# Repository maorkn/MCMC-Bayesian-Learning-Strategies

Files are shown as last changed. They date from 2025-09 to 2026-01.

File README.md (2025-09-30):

# Beyond Diffusion: Bayesian Learning Strategies in Single-Cell Life

**A comprehensive research framework for investigating predictive learning, memory formation, and Bayesian inference at the cellular level**

This repository contains the complete codebase, experimental platforms, and documentation for the paper **"Beyond Diffusion: Bayesian Learning Strategies in Single-Cell Life"**. The project demonstrates that single-celled organisms might exhibit sophisticated learning behaviors that extend beyond simple chemical diffusion, employing Bayesian-like inference strategies for environmental prediction and adaptive responses.

---

## Table of Contents

- [Overview](#overview)
- [Repository Structure](#repository-structure)
- [Research Components](#research-components)
  - [1. MBS Simulation](#1-mbs-simulation)
  - [2. Microscope-Mounted Chemostat](#2-microscope-mounted-chemostat)
  - [3. Smart Incubator](#3-smart-incubator)
  - [4. Manuscript](#4-manuscript)
- [Key Findings](#key-findings)
- [Getting Started](#getting-started)
- [Research Applications](#research-applications)
- [Hardware Platforms](#hardware-platforms)
- [Citation](#citation)
- [License](#license)
- [Contact](#contact)

---

## Overview

This research investigates whether single-celled organisms possess the capacity for **predictive learning** through Bayesian-like inference mechanisms that operate at sub-neural scales. The project combines:

1. **Agent-Based Simulations**: Computational models comparing Markovian-Bayesian Agents (MBAs) with memory-based learning against Blind Agents (BAs) that react only to current stimuli
2. **Experimental Validation**: Two custom-built automated platforms for long-term, high-precision biological experiments
3. **Theoretical Framework**: Mathematical models of cellular learning grounded in Bayesian inference and information theory

### Core Hypothesis

Single-celled organisms can:
- **Learn temporal associations** between environmental cues and subsequent stressors
- **Form cellular memories** that influence future behavioral responses
- **Predict environmental changes** using past experience encoded in molecular states
- **Optimize fitness** through anticipatory rather than purely reactive strategies

---

## Repository Structure

```
MCMC-Bayesian-Learning-Strategies/
├── README.md                           # This file
├── Manuscript/
│   └── Draft_18_09_25.tex             # LaTeX manuscript source
├── MBS_simulation/
│   └── MBA vs BA sim/                 # Agent-based simulation framework
│       ├── README.md                  # Simulation documentation
│       ├── mba_vs_ba_sim/            # Core simulation package
│       ├── wrappers/                  # Experiment wrappers
│       └── Fig_pub/                   # Publication figure generation
├── Microscope_mounted_chemostat/
│   ├── README.md                      # Platform documentation (400+ lines)
│   ├── Firmware/                      # ESP32 MicroPython code
│   ├── Hardware/                      # PCB Gerbers + 3D models
│   └── Docs/                          # Specifications & methods
└── Smart_incubator/
    ├── README.md                      # Platform documentation (400+ lines)
    ├── Firmware/                      # ESP32 MicroPython code (21 files)
    ├── Hardware/                      # PCB schematics + 3D models
    └── Docs/                          # Specifications, methods & analysis
```

---

## Research Components

### 1. MBS Simulation

**Location**: `MBS_simulation/MBA vs BA sim/`

**Purpose**: Agent-based simulations comparing learning strategies in evolutionary contexts.

#### Key Features

- **Markovian-Bayesian Agents (MBAs)**: Organisms that maintain memory of environmental patterns and use Bayesian inference to predict future conditions
- **Blind Agents (BAs)**: Memory-less organisms that respond only to immediate stimuli
- **Moran Process**: Population dynamics simulation with fitness-dependent reproduction
- **Multiple Experimental Paradigms**: Stress tests, genetic lock-in, continuous sweeps, topology scans

#### Agent Types

| Agent Type | Memory | Learning | Prediction | Fitness Strategy |
|---|---|---|---|---|
| MBA (Markovian-Bayesian) | ✓ | ✓ | ✓ | Anticipatory preparation |
| BA (Blind Agent) | ✗ | ✗ | ✗ | Reactive only |
| MBA-Gauss | ✓ | ✓ | ✓ | Gaussian environment model |

#### Simulation Capabilities

- **Population Evolution**: Track strategy dominance over thousands of generations
- **Fitness Landscapes**: Analyze preparatory response costs and benefits
- **Parameter Sweeps**: Systematic exploration of correlation, memory cost, environment variability
- **Statistical Analysis**: Permutation tests, effect size calculations, publication-ready visualizations

#### Quick Start

```bash
cd "MBS_simulation/MBA vs BA sim"
python -m wrappers.vanilla    # Basic MBA vs BA comparison
python -m wrappers.stress     # Stress test scenarios
```

**Documentation**: See `MBS_simulation/MBA vs BA sim/README.md` for detailed usage and `CLEANED_REPOSITORY_SUMMARY.md` for architecture overview.

---

### 2. Microscope-Mounted Chemostat

**Location**: `Microscope_mounted_chemostat/`

**Purpose**: Real-time microfluidic platform for studying habituation, valence reassignment, and threshold adaptation under microscopic observation.

#### Platform Capabilities

**Experimental Control:**
- **4-Pump Peristaltic System**: Independent control of 4 culture chambers
- **Variable Flow Rates**: 0-100% PWM control (13-bit resolution)
- **Programmable Protocols**: Chemostat, turbidostat, morbidostat modes
- **Temporal Precision**: Microsecond-level timing for stimulus delivery
- **Long-Term Stability**: Continuous operation for days to weeks

**Operational Modes:**
1. **Chemostat Mode**: Constant dilution rate, steady-state growth
2. **Turbidostat Mode**: Optical density (cellpose) feedback control
3. **Morbidostat Mode**: Dynamic drug concentration adjustment
4. **Custom Protocols**: User-defined temporal sequences

**Real-Time Integration:**
- **Microscope Compatibility**: Mounts directly on inverted microscopes
- **Cellpose Integration**: Optional AI-based cell counting
- **MQTT Communication**: Remote monitoring and control
- **Live Imaging**: Synchronized with image acquisition systems

#### Hardware Specifications

| Component | Specification | Function |
|---|---|---|
| Microcontroller | ESP32-WROOM-32 (240 MHz dual-core) | System control |
| Pumps | 4× Peristaltic pumps | Media delivery (intake, waste, 2× drugs) |
| LED Control | PWM-controlled illumination | Growth chamber lighting |
| Communication | WiFi (MQTT protocol) | Remote operation |
| Cost | $250-$840 | Depending on pump choice |

#### Research Applications

- **Habituation Studies**: Long-term adaptation to repeated chemical stressors
- **Valence Reassignment**: Testing whether organisms reassign meaning to previously neutral cues
- **Threshold Adaptation**: Investigating changes in stress response thresholds
- **Chemotaxis Experiments**: Studying gradient-following behavior
- **Drug Resistance Evolution**: Real-time observation of resistance emergence

#### Quick Start

```bash
# 1. Upload firmware to ESP32
cd Microscope_mounted_chemostat/Firmware
# Use Thonny or ampy to upload *.py files

# 2. Calibrate pumps
python local_pump_calibration.py

# 3. Run experiment
python chemostat_controller.py
```

**Full Documentation**: See `Microscope_mounted_chemostat/README.md` (400+ lines) and `Docs/parts_list.md` for complete BOM.

---

### 3. Smart Incubator

**Location**: `Smart_incubator/`

**Purpose**: Autonomous platform for testing predictive learning through controlled temporal associations between environmental cues and thermal stressors.

#### Platform Capabilities

**Thermal Control System:**
- **Dual Actuators**: PTC heater + TEC1 Peltier cooler
- **PID Regulation**: Custom-tuned controller (Kp=6.0, Ki=0.02, Kd=1.5)
- **Temperature Range**: 15-40°C (software limited for biological safety)
- **Precision**: ±0.5°C at basal (23°C), ±0.8°C during heat shock (32°C)
- **Rapid Transitions**: 2-3 min heating, 5-8 min cooling

**Multi-Modal Stimulus Delivery:**
- **Optical (LED)**: High-brightness white LED with 16-bit PWM control
- **Mechanical (Vibration)**: Programmable vibration motor with pulsing patterns
- **Combined Modes**: Independent or simultaneous multi-modal delivery
- **Temporal Precision**: Microsecond-level timing accuracy

**Experimental Protocol Framework:**

| Correlation Mode | Description | US-HS Timing | Measured Δt | Interpretation |
|---|---|---|---|---|
| 0 | Non-Temporal Control | Random | -58.1 ± 113.9 min | No predictive value |
| 1 | Temporal Predictive | US precedes HS | 30.0 ± 0.3 min | Perfect correlation |
| 2 | Temporal Post-stress | US follows HS | Variable | Reversed association |
| 3 | Testing Mode | Short cycle | 0.5 min | Hardware validation |

**Data Management:**
- **10-Second Sampling**: Complete system state snapshots
- **SD Card Logging**: FAT32 with SHA-256 checksums
- **Structured Hierarchy**: Experiment directories with metadata
- **Data Integrity**: Cryptographic verification and manifest tracking

**Safety Features:**
- **Temperature Failsafe**: Stuck sensor detection and overheat protection
- **Automated Recovery**: Sensor reinitialization and error resilience
- **Progressive Protection**: Graduated intervention based on severity
- **Memory Management**: Periodic garbage collection and heap monitoring

#### Hardware Specifications

| Component | Specification | Function |
|---|---|---|
| Microcontroller | ESP32-WROOM-32 (240 MHz dual-core) | System orchestration |
| Temperature Sensor | MAX31865 + PT100 RTD | Precision measurement |
| Heater | PTC element (5-15W) | Warming actuator |
| Cooler | TEC1 Peltier module | Cooling actuator |
| Stimuli | LED + vibration motor | Multi-modal cues |
| Display | SSD1306 128×64 OLED | Real-time status |
| Storage | MicroSD card (4-32 GB) | Data logging |
| Cost | $180-$320 | Depending on configuration |

#### Research Applications

- **Predictive Learning**: Testing temporal association between cues and stress
- **Memory Formation**: Examining cellular response persistence
- **Phenotypic Plasticity**: Multi-timescale environmental adaptation
- **Pre-Neural Learning**: Investigating sub-neural inference mechanisms
- **Complex Protocols**: Custom landscape execution with multi-parameter control

#### Quick Start

```bash
# 1. Format SD card as DOS_FAT_32 with MBR
diskutil eraseDisk MS-DOS INCUBATOR MBR /dev/diskX

# 2. Upload firmware to ESP32
cd Smart_incubator/Firmware
# Use Thonny or ampy to upload *.py files

# 3. Power on - system auto-initializes and starts cycles
# Monitor via OLED display or serial console
```

**Full Documentation**: See `Smart_incubator/README.md` (400+ lines) and `Docs/parts_list.md` for complete BOM.

## Getting Started

### Prerequisites

**For Simulations:**
```bash
# Python 3.8+ with scientific computing stack
pip install numpy scipy matplotlib pandas seaborn
```

**For Hardware Platforms:**
- ESP32 development boards
- MicroPython firmware (v1.24.1+)
- Electronic components (see respective parts lists)
- Basic electronics assembly skills

### Installation

**Clone Repository:**
```bash
git clone https://github.com/your-repo/MCMC-Bayesian-Learning-Strategies.git
cd MCMC-Bayesian-Learning-Strategies
```

**Run Simulations:**
```bash
cd "MBS_simulation/MBA vs BA sim"
python -m wrappers.vanilla
```

**Build Hardware:**
1. Review platform-specific README files for detailed instructions
2. Order components from parts_list.md BOMs
3. Follow assembly guides in respective Docs/ directories
4. Upload firmware and configure for your experiments

---

## Hardware Platforms

### Comparison Matrix

| Feature | Microscope-Mounted Chemostat | Smart Incubator |
|---|---|---|
| **Primary Use** | Real-time microscopy + microfluidics | Autonomous thermal learning experiments |
| **Control Variables** | Flow rates, drug concentrations, LED | Temperature, LED, vibration |
| **Observation** | Live imaging (Cellpose compatible) | End-point sampling + logging |
| **Chambers** | 4 independent cultures | 1 main chamber |
| **Duration** | Hours to days | Weeks to months |
| **Sampling** | Continuous video + OD sensing | 10-second data snapshots |
| **Correlation Modes** | Chemical gradients | 4 temporal correlation modes |
| **Cost** | $250-$840 | $180-$320 |
| **Build Difficulty** | Moderate (fluidics + optics) | Moderate (thermal + electronics) |

### Common Features

Both platforms share:
- **ESP32-based control** with MicroPython
- **PWM actuation** for precise analog control
- **SD card data logging** with integrity verification
- **Real-time monitoring** (MQTT/OLED display)
- **Safety systems** (sensor recovery, failsafes)
- **Modular design** for easy modification
- **Open-source firmware** and hardware designs

---

## Citation

If you use this work in your research, please cite:

```bibtex
@article{your_paper_2025,
  title={Beyond Diffusion: Bayesian Learning Strategies in Single-Cell Life},
  author={[Authors]},
  journal={[Journal]},
  year={2025},
  doi={[DOI]}
}
```

---

## License

[Specify license - e.g., MIT, GPL, CC-BY, etc.]

This repository contains:
- **Software**: Simulation code and firmware (specify license)
- **Hardware**: PCB designs and 3D models (specify license, e.g., CERN-OHL)
- **Documentation**: Guides and specifications (specify license, e.g., CC-BY-4.0)

---

## Contact

**Institution**: [IBE, CSIC Barcelona, MCG Lab ]  

### Contributing

We welcome contributions! Please:
1. Fork the repository
2. Create a feature branch
3. Submit a pull request with clear description

For hardware modifications, include:
- Updated BOMs
- Revised schematics/PCB files
- Testing notes and validation data

### Support

- **Issues**: Report bugs via GitHub Issues
- **Discussions**: Use GitHub Discussions for questions
- **Documentation**: Refer to platform-specific README files
- **Hardware**: See respective parts_list.md for component sourcing

---

## Project Status

**Current Version**: 1.0 (September 2025)

**Status**: 
- ✅ Simulations: Complete and validated
- ✅ Microscope-Mounted Chemostat: Built and operational
- ✅ Smart Incubator: Built and operational
- 🔄 Manuscript: Under review

**Roadmap**:
- [ ] Extended simulation parameter sweeps
- [ ] Additional experimental validation datasets
- [ ] Protocol library expansion
- [ ] Community hardware builds and feedback

---

**Repository Structure Last Updated**: September 30, 2025  
**Maintainers**: [Maor Knafo]  
**For questions or collaboration inquiries**: [Contact info]

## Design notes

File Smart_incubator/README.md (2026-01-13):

# Smart Incubator Platform

**An automated experimental platform for studying phenotypic plasticity, predictive learning, and cellular memory through precise environmental control**

The Smart Incubator is a sophisticated ESP32-based system designed to subject cell cultures to complex, long-term environmental protocols with precise temporal control. This platform enables researchers to test hypotheses about biological prediction, memory formation, and adaptive plasticity at the cellular level—providing insights into the evolutionary origins of learning behaviors that preceded neural systems.

---

## Table of Contents

- [Overview](#overview)
- [Key Capabilities](#key-capabilities)
- [System Architecture](#system-architecture)
- [Hardware Components](#hardware-components)
- [Quick Start](#quick-start)
- [Experimental Protocols](#experimental-protocols)
- [Data Management](#data-management)
- [Documentation](#documentation)
- [Safety Features](#safety-features)
- [Troubleshooting](#troubleshooting)

---

## Overview

The Smart Incubator creates a controllable "learning environment" where organisms experience either predictable or unpredictable relationships between environmental cues (conditional stimuli) and subsequent stressors (heat shocks). This design allows researchers to:

- **Test predictive learning capacity** in microorganisms through temporal association experiments
- **Study memory formation** by examining cellular responses to learned cue-stress relationships
- **Investigate phenotypic plasticity** across multiple time scales and environmental conditions
- **Explore pre-neural learning** mechanisms at the single-cell and population levels

### Design Philosophy

The platform emphasizes:
- **Long-term autonomy**: Runs multi-week experiments without intervention
- **Temporal precision**: Microsecond-level control of stimulus timing
- **Data integrity**: Comprehensive logging with cryptographic verification
- **Operational resilience**: Automated recovery from transient failures
- **Experimental flexibility**: Support for diverse correlation modes and custom protocols

### Research Applications

**Predictive Learning Studies:**
- Temporal association between environmental cues and thermal stress
- Correlation-dependent phenotypic responses
- Memory formation and decay dynamics

**Habituation Research:**
- Long-term adaptation to repeated stress cycles
- Valence reassignment experiments
- Threshold modification studies

**Complex Protocol Execution:**
- Multi-parameter landscape experiments
- Synchronized multi-modal stimulus delivery
- Adaptive protocol adjustment during runtime

---

## Key Capabilities

### Thermal Control System

**Dual-Actuator Temperature Regulation:**
- **PTC Heater**: Programmable heating from ambient to 40°C
- **TEC1 Peltier Cooler**: Active cooling below ambient temperature
- **PID Control**: Custom-tuned controller (Kp=6.0, Ki=0.02, Kd=1.5)
- **Precision**: ±0.5°C at basal temperature (23°C), ±0.8°C during heat shock (32°C)
- **Rapid Transitions**: 2-3 minute heating, 5-8 minute cooling times

**Temperature Sensing:**
- MAX31865 RTD-to-digital converter with PT100 platinum sensor
- Advanced noise filtering with median-of-5 sampling
- Fault detection and automatic sensor recovery
- Temperature range: 15-40°C (software limited for biological safety)

### Multi-Modal Stimulus Delivery

**Optical Stimulation (LED):**
- High-brightness white LED with PWM intensity control
- 16-bit resolution (65,535 discrete levels)
- Instantaneous on/off switching
- Configurable intensity (default: 25%)

**Mechanical Stimulation (Vibration Motor):**
- Miniature vibration motor with PWM amplitude control
- Programmable pulsing patterns (default: 20s on, 60s off)
- Thermal protection via duty cycling
- Configurable intensity (default: 100%)

**Combined Modes:**
- Independent control of each modality
- Simultaneous multi-modal delivery
- Temporal precision: microsecond-level timing accuracy

### Experimental Protocol Framework

**Correlation Modes** (Testing Predictive Relationships):

| Mode | Description | US-HS Timing | Measured Δt | Biological Interpretation |
|---|---|---|---|---|
| 0 | Non-Temporal Control | Random | -58.1 ± 113.9 min | No predictive value |
| 1 | Temporal Predictive | US precedes HS | 30.0 ± 0.3 min | Perfect correlation |
| 2 | Temporal Post-stress | US follows HS | Variable | Reversed association |
| 3 | Testing Mode | Short cycle | 0.5 min | Hardware validation |

**Cycle-Based Design:**
- Randomized cycle durations (200-400 minutes) prevent temporal entrainment
- Distinct basal and heat shock phases within each cycle
- Long-term stability: weeks of continuous operation
- Automated parameter management and state preservation

### Advanced Features

**Data Acquisition:**
- 10-second sampling rate with complete system snapshots
- Real-time logging to SD card with FAT32 compatibility
- SHA-256 checksums for data integrity verification
- Comprehensive metadata and provenance tracking

**Safety and Resilience:**
- Temperature failsafe with stuck sensor detection
- Automated sensor recovery system
- Hardware protection with progressive response mechanisms
- Memory management via periodic garbage collection
- Robust initialization with exponential backoff retry

**User Interfaces:**
- Real-time OLED status display (128×64 SSD1306)
- Optional web server for remote monitoring
- Serial console with detailed diagnostic output
- Comprehensive diagnostic tools built-in

---

## System Architecture

### Multi-Layer Software Architecture

```
┌─────────────────────────────────────────────────────────┐
│  Application Layer: main.py → run_experiment_cycle.py  │
├─────────────────────────────────────────────────────────┤
│  Control Layer: temp_controller.py → us_control.py     │
├─────────────────────────────────────────────────────────┤
│  Hardware Layer: max31865.py → sd_logger.py → oled     │
├─────────────────────────────────────────────────────────┤
│  Driver Layer: heater.py → tec.py → led → vibration    │
├─────────────────────────────────────────────────────────┤
│  Boot Layer: boot.py (GPIO securing, initialization)   │
└─────────────────────────────────────────────────────────┘
```

### Core Components

**System Orchestration (`main.py`):**
- Hardware initialization with 5-attempt retry logic
- Global parameter management (temperature, timing, correlation modes)
- Continuous cycle execution with error tracking
- Memory management and heap monitoring

**Experiment Logic (`run_experiment_cycle.py`):**
- Random cycle length generation (200-400 minutes)
- Phase transition management (basal → heat shock)
- Correlation-based stimulus timing
- Real-time data collection (10-second intervals)

**Temperature Regulation (`temp_controller.py`):**
- Dual-actuator PID control system
- Anti-windup protection and target change detection
- PWM interference mitigation
- Temperature validation and fault recovery

**Stimulus Management (`us_control.py`):**
- Multi-modal control (LED, vibration, or both)
- Configurable timing patterns
- State tracking and status reporting
- Temperature-synchronized operation

**Data Management (`sd_logger.py`):**
- Structured directory hierarchy
- JSON-based logging with checksums
- Manifest system for file integrity
- Thread-safe operations with mutex locks

**Hardware Drivers:**
- `max31865.py`: PT100 RTD temperature sensor with advanced filtering
- `heater.py`, `tec.py`: Thermal actuator PWM control
- `led_control.py`, `vibration_control.py`: Stimulus delivery drivers
- `oled_display.py`: Real-time status interface

**Safety Systems:**
- `temperature_failsafe.py`: Comprehensive protection mechanisms
- `sensor_recovery.py`: Automated sensor restoration
- `sensor_diagnostic.py`: Health monitoring and troubleshooting

---

## Hardware Components

### Electronic Components

| Component | Model/Spec | Function | Interface |
|---|---|---|---|
| Microcontroller | ESP32-WROOM-32 | System control (240 MHz dual-core) | — |
| Temperature Sensor | MAX31865 + PT100 RTD | Precision temperature measurement | SPI (VSPI): SCK 18, MOSI 23, MISO 19, CS 5 |
| Heater | PTC Heating Element | Warming actuator | PWM Pin 33 (MOSFET-controlled) |
| Cooler | TEC1 Peltier Module | Cooling actuator | PWM Pin 27 (MOSFET-controlled) |
| LED | High-brightness white LED | Optical stimulus | PWM Pin 25 |
| Vibration Motor | Miniature motor | Mechanical stimulus | PWM Pin 16 |
| SD Card Module | MicroSD (SPI) | Data storage | HSPI: SCK 14, MOSI 13, MISO 12, CS 15 |
| Display | SSD1306 128×64 OLED | Real-time status | I2C: SCL 22, SDA 21 |
| MOSFETs | IRFZ44N or IRLZ44N | Power switching | Various control pins |

### Pin Assignments

**Power Control:**
- Pin 27: TEC1 cooler control
- Pin 33: PTC heater control
- Pin 25: LED control
- Pin 16: Vibration control

**SPI Bus (Temperature & SD Card):**
- SCK 14: HSPI Clock
- MOSI 13: HSPI MOSI
- MISO 12: HSPI MISO
- CS 5: MAX31865 Chip Select
- CS 15: SD Card Chip Select

**I2C Bus (Display):**
- SCL 22: I2C Clock
- SDA 21: I2C Data

### Physical Design Files

**PCB Design:**
- KiCad schematic file included in `Hardware/PCB/`
- ESP32-DEVKITC-32D footprint
- MOSFET power control circuits
- Sensor interfacing

---

## Quick Start

### 📱 WiFi Configuration Mode (v2.0)

The Smart Incubator now features a **phone-based WiFi setup** mode. On boot, the ESP32 creates its own WiFi hotspot, allowing you to configure experiments directly from your phone without modifying code.

**How to use:**

1. **Power on the ESP32** → It creates a WiFi hotspot with unique SSID (e.g., `Inc-6774`)
2. **Connect your phone** to the WiFi network
   - SSID: `Inc-XXXX` (where XXXX is your device's unique ID)
   - Password: `incubator123`
3. **Open a browser** and go to `http://192.168.4.1`
4. **Set the time** → Click "Use Phone Time" to sync automatically
5. **Configure your experiment:**
   - Experiment name
   - Correlation value (-1 to +1)
   - Temperature settings
   - Interval and duration parameters
6. **Press "START EXPERIMENT"** → The incubator begins running
7. **Disconnect from WiFi** → The experiment runs autonomously

**Multiple Incubators:** Each device gets a unique SSID based on its MAC address, so you can run multiple incubators simultaneously without WiFi conflicts.

**Correlation Values:**
| Value | Meaning |
|---|---|
| +1.0 | US always precedes heat shock (paired/predictive) |
| 0.0 | US delivered randomly (control) |
| -1.0 | No US delivered |

---

### ⚡ Fast Track (Recommended)

**For complete deployment instructions, see:**
- 📘 **[DEPLOYMENT_GUIDE.md](DEPLOYMENT_GUIDE.md)** - Complete deployment documentation
- 🚀 **[QUICK_START.md](QUICK_START.md)** - Visual workflows and examples

**Quick commands:**

```bash
# 1️⃣ First time setup (blank ESP32)
python Smart_incubator/sync_firmware.py --correlation 1 --yes

# 2️⃣ Redeploy with alternate correlation (control runs)
python Smart_incubator/sync_firmware.py --correlation 0 --yes

# 3️⃣ Deploy the post-training survival test firmware
python Smart_incubator/sync_firmware.py --yes --entry-script main_test.py

# (Windows example if auto-detect misses COM port)
python Smart_incubator/sync_firmware.py --correlation 1 --yes --port COM3

# 4️⃣ Format SD card - see SD Card Formatting section below

# 5️⃣ Or use VS Code (even easier!)
# Press Ctrl+Shift+B to deploy (pick correlation + entry script in the prompt)
# Press Ctrl+Shift+P → "Tasks: Run Task" → choose task
```

> 💡 Set `INCUBATOR_PORT=COM3` (Windows) or `ESP32_PORT=/dev/ttyUSB0` (Linux/macOS) to skip `--port` each time.
> ℹ️ `sync_firmware.py` auto-detects `mpremote` (`mpremote`, `py -m mpremote`, `python -m mpremote`, etc.) and prints the command it will use. Set `MPREMOTE="path/to/mpremote"` if you need a custom executable.

**Available VS Code Tasks:**
- **Sync Firmware (Full Redeploy)** - Safe redeploy with correlation + entry-script picker (default: `Ctrl+Shift+B`)
- **Format SD Card** - Clean SD card for new experiments
- **Deploy Core HES Modules** - Upload only HES system files
- **Deploy Full Firmware** - Upload all firmware files
- **Deploy Config Files Only** - Upload experiment configs
- **Open REPL** - Interactive Python shell
- **Run Experiment** - Start an experiment
- **List Files on Device** - Show ESP32 filesystem
- **Reset Device** - Soft reset ESP32

---

### � SD Card Formatting

**Two methods available depending on your needs:**

#### Method 1: Full Local Reformat (Recommended for new/corrupted cards)
Creates a fresh FAT32 (MBR) filesystem with required directories.

**macOS:**
```bash
# List available disks
diskutil list
python3 Smart_incubator/format_sd_card_local.py --list

# Format (replace disk6 with your SD card identifier)
python3 Smart_incubator/format_sd_card_local.py /dev/disk6

# Eject safely
diskutil eject /dev/disk6
```

**Linux:**
```bash
# List available disks
lsblk
python3 Smart_incubator/format_sd_card_local.py --list

# Format (replace sdb with your SD card identifier)
sudo python3 Smart_incubator/format_sd_card_local.py /dev/sdb

# Eject safely
sudo eject /dev/sdb
```

#### Method 2: ESP32 Cleanup (Quick cleanup for existing cards)
Clears files without reformatting the filesystem.

```bash
python3 Smart_incubator/format_sd_card.py
```

**When to use each method:**
- **Full reformat**: New cards, corrupted filesystems, or complete reset needed
- **ESP32 cleanup**: Quick data wipe between experiments on working cards

📘 **For detailed instructions and troubleshooting, see [SD_CARD_FORMATTING_GUIDE.md](SD_CARD_FORMATTING_GUIDE.md)**

---

The Smart Incubator includes sophisticated deployment automation:

#### 1. **Full Redeploy Sync** (`sync_firmware.py`)
Safe, repeatable firmware deployment every time:
- Installs a temporary safe boot, wipes the device, and re-uploads all firmware
- Automatically reconfigures the SD card structure and required packages
- Optional `--correlation 0|1` flag rewrites `main.py` before upload so you never edit by hand
- Optional `--entry-script main_test.py` installs the survival-test harness as `/main.py` (default is the training runtime)
- `--yes` (or the VS Code task) skips prompts for unattended reflashes
- Auto-detects the ESP32 port, with `--port` override when needed
- Validates the `mpremote` command before flashing and falls back through multiple launchers; override with `MPREMOTE` if your setup is non-standard

#### 2. **SD Card Formatter** (`format_sd_card.py`)
Prepares SD card with proper structure:
- Removes all experiment data
- Clears old config files  
- Creates fresh directory structure
- Shows storage statistics
- Requires double confirmation for safety

#### 3. **Manual Deployment** (`deploy.sh`)
Traditional deployment script for specific scenarios:
- Core modules only
- Full firmware
- Config files only

---

### Prerequisites

**Hardware Setup:**
1. ESP32 development board properly wired according to pin assignments
2. MAX31865 + PT100 RTD sensor installed
3. PTC heater and TEC cooler with MOSFET drivers
4. LED and vibration motor connected
5. SD card formatted as DOS_FAT_32 with MBR partition scheme
6. SSD1306 OLED display (optional but recommended)

**Software Requirements:**
- MicroPython firmware (ESP32-GENERIC v1.24.1 or later)
- All firmware files from `Firmware/` directory uploaded to ESP32

### Installation Steps

1. **Format SD Card:**
   See the **SD Card Formatting** section above for complete instructions.
   - For new cards: Use full local reformat method
   - For existing cards: Use ESP32 cleanup method

2. **Upload Firmware:**
   Upload all `.py` files from `Firmware/` to ESP32 root directory using Thonny or ampy:
   ```bash
   ampy -p /dev/ttyUSB0 put boot.py
   ampy -p /dev/ttyUSB0 put main.py
   # ... (upload all firmware files)
   ```

3. **Verify Installation:**
   ```python
   # Run on ESP32 via REPL:
   import os
   print(os.listdir())
   # Confirm all required files are present
   ```

4. **Test Hardware:**
   ```python
   # Run hardware test suite:
   import Tests
   Tests.main()
   ```

5. **Power On:**
   - System will automatically initialize
   - Check OLED display for status
   - Monitor serial console for detailed logging

### Default Configuration

**Temperature Settings:**
- Basal temperature: 23°C
- Heat shock temperature: 32°C

**Cycle Parameters:**
- Duration: 200-400 minutes (randomized)
- US duration: 30 seconds
- Heat shock duration: 30 minutes

**Stimulus Configuration:**
- Type: Both LED and vibration
- LED intensity: 25%
- Vibration intensity: 100%
- Vibration pattern: 20s on / 60s off

**Correlation Mode:**
- Default: Mode 1 (US precedes heat shock by 30 minutes)

**Data Logging:**
- Sampling rate: Every 10 seconds
- Directory: `/sd/data/DDMMYYYY_correlation/`
- Format: JSON with SHA-256 checksums

---

## Experimental Protocols

### Standard Temporal Learning Protocol

**Goal:** Test whether organisms can learn to predict heat shock based on prior sensory cues.

**Configuration:**
```python
# In main.py:
basal_temp = 23.0      # Optimal growth temperature
heat_shock_temp = 32.0  # Stress temperature
correlation = 1         # US precedes heat shock
min_interval = 200      # Minimum cycle length (minutes)
max_interval = 400      # Maximum cycle length (minutes)
us_duration = 0.5       # US duration (minutes)
heat_duration = 30      # Heat shock duration (minutes)
```

**Experimental Timeline:**
1. **Basal Phase** (variable 170-370 min): Maintain 23°C
2. **US Delivery** (30 sec): Present LED/vibration stimulus
3. **Predictive Interval** (30 min): Continue at 23°C
4. **Heat Shock** (30 min): Increase to 32°C
5. **Recovery** (2-5 min): Return to basal conditions
6. **Repeat**: Begin next randomized cycle

**Expected Outcomes:**
- **Correlation = 1**: Cells may develop anticipatory responses to US
- **Correlation = 0**: No predictive relationship (control)

### Non-Temporal Control Protocol

**Goal:** Verify that responses are due to temporal association, not stimulus intensity.

**Configuration:**
```python
correlation = 0  # Random independent timing
# All other parameters identical to standard protocol
```

### Complex Landscape Execution

**Goal:** Run pre-programmed multi-parameter protocols.

**Setup:**
1. Create CSV landscape file with time-series data
2. Place in `/sd/` directory
3. Launch with `landscape_executor_enhanced.py`

**Features:**
- Simultaneous temperature, LED, and vibration control
- Complex waveforms (sinusoidal, ramp, step functions)
- Multi-day automated execution

---

## Data Management

### Directory Structure

```
/sd/data/
├── [DDMMYYYY_correlation]/       # Experiment directory
│   ├── meta.json                 # Experiment metadata
│   ├── manifest.json             # File integrity manifest
│   ├── cycle_N_TIMESTAMP.json    # Data snapshots (10-sec intervals)
│   └── cycle_N_summary.json      # End-of-cycle statistics
```

### Data File Formats

**Metadata (`meta.json`):**
```json
{
  "experiment_id": "9298_1",
  "start_time": 1635724800,
  "basal_temp": 23.0,
  "heat_shock_temp": 32.0,
  "correlation": 1,
  "firmware_version": "1.0.0"
}
```

**Data Snapshot (`cycle_N_TIMESTAMP.json`):**
```json
{
  "timestamp": 18883,
  "temp": 31.63,
  "set_temp": 23.0,
  "power": -89.55,
  "mode": "Cooling",
  "tec_state": "On",
  "us_active": 0,
  "elapsed_minutes": 0.17,
  "cycle_length": 242,
  "phase": "basal",
  "cycle_num": 2
}
```

**Cycle Summary (`cycle_N_summary.json`):**
```json
{
  "cycle": 5,
  "duration": 245.3,
  "temp_min": 22.8,
  "temp_max": 32.5,
  "temp_mean": 24.1,
  "temp_std": 3.2,
  "error_count": 0,
  "us_deliveries": 1,
  "heat_shock_success": true
}
```

### Data Integrity

**Cryptographic Verification:**
- SHA-256 checksums for all data files
- Manifest tracking with verification
- Automatic corruption detection

**Quality Assurance:**
- Range checking on sensor readings
- Temporal consistency validation
- Cross-parameter logical checks
- Missing data detection and flagging

### Analysis Tools

**Built-in Scripts:**
- `plot_experiment_data.py`: Visualization of cycle data
- `custom_analysis_*.py`: Statistical analysis examples
- Export utilities for external platforms

**Python Analysis (Run on PC):**
```python
import json
import matplotlib.pyplot as plt

# Load cycle data
with open('cycle_10_154510.json') as f:
    data = json.load(f)

# Plot temperature over time
plt.plot(data['timestamp'], data['temp'])
plt.xlabel('Time (s)')
plt.ylabel('Temperature (°C)')
plt.show()
```

---

## Documentation

### Included Documentation Files

**Core Documentation (`Docs/`):**
- `Smart Incubator Platform M&M.md`: Comprehensive methods and materials
- `Smart Incubator Platform M&M.tex`: LaTeX version for manuscript preparation
- `README.md` (this file): System operation guide
- `materials_and_methods.md`: Detailed experimental protocols

**Technical Specifications:**
- `BUG_ANALYSIS_AND_SOLUTION.md`: Critical bug fixes and failsafe solutions
- `SENSOR_RECOVERY_SOLUTION.md`: Enhanced sensor recovery documentation
- `PLOTTING_GUIDE.md`: Data visualization best practices

**Advanced Features:**
- `README_landscape.md`: Landscape mode protocol guide
- `landscape_documentation.md`: Advanced landscape executor details

### Firmware Documentation

Each firmware module includes comprehensive docstrings:
- Module purpose and architecture
- Class and function documentation
- Parameter descriptions and ranges
- Error handling procedures
- Usage examples

Access via REPL:
```python
import temp_controller
help(temp_controller)
```

---

## Safety Features

### Temperature Failsafe System

**Protective Mechanisms:**
1. **Stuck Sensor Detection**: Identifies frozen temperature readings
2. **Overheat Protection**: Emergency shutdown above safety threshold
3. **Progressive Response**: Graduated intervention based on severity
4. **Hardware Protection**: Automatic actuator disabling on critical errors

**Failsafe Triggers:**
- Sensor reading unchanged for >5 minutes
- Temperature exceeds 45°C (biological safety limit)
- Sensor fault flags from MAX31865
- Repeated temperature validation failures

**Response Actions:**
- Level 1: Increase monitoring frequency
- Level 2: Disable heating actuators
- Level 3: Enable cooling system
- Level 4: Complete system shutdown with error logging

### Automated Sensor Recovery

**Recovery System:**
- Detects stuck or noisy sensor readings
- Attempts automated sensor reinitialization
- Multi-stage recovery protocol
- Continues experiment if recovery successful

**Recovery Procedure:**
1. Identify anomalous readings (change < 0.01°C for 5 min)
2. Temporarily disable PWM interference sources
3. Power cycle sensor via SPI reset
4. Verify restored functionality
5. Resume normal operation or escalate to failsafe

### Error Resilience

**Initialization Resilience:**
- Up to 5 retry attempts for hardware components
- Exponential backoff delays between attempts
- Cleanup and reset between retries
- Detailed error logging for diagnostics

**Operational Resilience:**
- Graceful degradation on non-critical failures
- Continue operation without display if OLED fails
- Experiment continues if logging fails (with warnings)
- Consecutive error tracking with automatic restart

**Memory Management:**
- Periodic garbage collection (every 5 minutes)
- Heap monitoring and leak detection
- Global variable cleanup between cycles
- Resource cleanup on errors

---

## Troubleshooting

### Common Issues and Solutions

#### SD Card Initialization Failed

**Symptoms:** "SD card initialization failed" on startup

**Causes:**
- Incorrect SD card format (must be DOS_FAT_32 with MBR)
- Missing `/data/` directory
- Poor quality SD card
- Loose connections

**Solutions:**
1. Reformat SD card properly:
   ```bash
   # macOS:
   sudo diskutil eraseDisk MS-DOS INCUBATOR MBR /dev/diskX
   ```
2. Manually create `/data/` directory
3. Try a different high-quality SD card (Class 10 recommended)
4. Check SPI wiring (pins 12, 13, 14, 15)

#### Temperature Sensor Not Responding

**Symptoms:** Constant temperature readings or sensor errors

**Causes:**
- Loose RTD connections
- SPI communication issues
- PT100 sensor failure
- Incorrect reference resistor

**Solutions:**
1. Run sensor diagnostic:
   ```python
   import sensor_diagnostic
   sensor_diagnostic.run_full_diagnostic()
   ```
2. Check all RTD wiring (2, 3, or 4-wire configuration)
3. Verify 430Ω reference resistor installed correctly
4. Test with known-good sensor

#### Display Not Working

**Symptoms:** OLED shows no output or garbled display

**Causes:**
- Missing `ssd1306.py` library
- I2C address mismatch (0x3C vs 0x3D)
- I2C wiring issues
- Power supply insufficient

**Solutions:**
1. Verify `ssd1306.py` uploaded to ESP32
2. Try alternate I2C address in `oled_display.py`
3. Check I2C connections (pins 21, 22)
4. Ensure stable 3.3V/5V power supply
5. System continues without display—not critical

#### Temperature Control Unstable

**Symptoms:** Temperature oscillates or overshoots target

**Causes:**
- PID parameters need tuning
- PWM frequency too high/low
- Thermal mass insufficient
- Actuator sizing issues

**Solutions:**
1. Run PID tuning guide:
   ```python
   import pid_tuning_guide
   pid_tuning_guide.run_auto_tune()
   ```
2. Adjust PID constants in `temp_controller.py`
3. Increase thermal mass of chamber
4. Verify heater/cooler power ratings adequate

#### Experiment Not Starting

**Symptoms:** System initializes but cycles don't begin

**Causes:**
- Parameter configuration errors
- Hardware component initialization failed
- Memory issues
- Critical error state

**Solutions:**
1. Check serial console for error messages
2. Verify all parameters valid in `main.py`
3. Run hardware test suite:
   ```python
   import Tests
   Tests.main()
   ```
4. Power cycle system for fresh start
5. Check available heap memory

### Diagnostic Tools

**Built-in Diagnostics:**
```python
# Comprehensive sensor diagnostic
import sensor_diagnostic
sensor_diagnostic.run_full_diagnostic()

# SD card verification
import sd_logger
sd_logger.verify_sd_integrity()

# Hardware component test
import Tests
Tests.main()

# Memory status
import gc
gc.collect()
print(f"Free heap: {gc.mem_free()} bytes")
```

**Serial Console Monitoring:**
- Connect via USB serial (115200 baud)
- Real-time system status messages
- Detailed error reporting
- Component initialization logs

### Getting Help

**Diagnostic Information to Collect:**
1. Complete serial console output
2. SD card contents (especially `meta.json` and error logs)
3. Hardware configuration details
4. Firmware file list and versions
5. Description of observed behavior vs. expected

**Reporting Issues:**
- Document exact steps to reproduce
- Include all diagnostic tool outputs
- Note any recent changes to hardware/software
- Provide photos of hardware setup if relevant

---

## Advanced Features

### Web Server Mode

Optional remote monitoring and control interface:

```python
# Use main_with_server.py instead of main.py
# Access via browser at ESP32's IP address
# Features:
# - Real-time temperature display
# - Current cycle status
# - Parameter adjustment
# - System health monitoring
```

### Landscape Executor

Execute complex pre-programmed protocols:

```python
import landscape_executor_enhanced

# Load and execute CSV-based protocol
landscape_executor_enhanced.run_landscape('complex_protocol.csv')

# Features:
# - Multi-parameter control
# - Complex waveforms
# - Long-duration experiments
# - Synchronized multi-modal delivery
```

### Custom Analysis Pipeline

Built-in analysis scripts for data processing:

```python
# Generate publication-ready figures
python custom_analysis_0_0_publish_ready.py

# Correlation analysis
python custom_analysis_comparison_improved.py

# Exploratory analysis
python custom_analysis_exploratory_publication.py
```

---

## Research Context

### Manuscript Integration

This platform is described in the manuscript:

**"Beyond Diffusion: Bayesian Learning Strategies in Single-Cell Life"**

The Smart Incubator specifically supports experiments testing:
- Cue-based learning in microorganisms
- Valence assignment to environmental stimuli
- Prediction and memory at the cellular level
- Pre-neural Bayesian inference mechanisms

### Experimental Design Rationale

**Temporal Correlation Paradigm:**
The ability to create predictable vs. unpredictable cue-stress relationships allows direct testing of whether organisms use Bayesian-like inference to predict environmental changes.

**Randomized Cycle Lengths:**
Variable cycle durations prevent organisms from using simple timing

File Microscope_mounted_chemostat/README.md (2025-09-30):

# Microscope Mounted Chemostat

An experimental platform for studying habituation, valence reassignment, and threshold adaptation in single-celled organisms such as *Capsaspora owczarzaki*.

## Overview

The Microscope Mounted Chemostat (MCMC platform) is an automated experimental system designed to convert standard laboratory microscopes into sophisticated continuous culture reactors with real-time cell counting and adaptive control capabilities. Built on ESP32 microcontrollers with MicroPython firmware, the system enables long-term microbiology experiments with precise environmental control.

**Key Features:**
- **Four-pump coordination system** for continuous culture
- **Variable PWM flow control** (0-100% duty cycle)
- **Real-time cell counting** via Cellpose integration (optional)
- **Multiple operation modes:** Chemostat, Turbidostat, Morbidostat
- **Microscope integration** for longitudinal imaging
- **Under-lens chemical pulses** with reproducible transients
- **Closed-loop control** based on live segmentation

## Directory Structure

```
Microscope_mounted_chemostat/
├── Docs/                          # Documentation and specifications
│   ├── MCMC_Software_Spec.md     # Complete software architecture
│   ├── MCMC_Methods_Materials.tex # Methods from manuscript
│   ├── MCMClayout.drawio.png     # System diagram
│   └── parts_list.md             # Bill of materials (to be created)
├── Firmware/                      # ESP32 MicroPython code
│   ├── chemostat_controller.py   # Main controller with flow control
│   ├── local_pump_calibration.py # Pump calibration utility
│   ├── esp_c_controller.py       # Channel controller
│   ├── config.py                 # Configuration settings
│   ├── main.py                   # Entry point
│   ├── boot.py                   # Boot configuration
│   └── Hardware_modules/         # Hardware drivers
│       ├── pump_controller.py    # Pump control module
│       └── led_controller.py     # LED control module
└── Hardware/                      # Physical design files
    ├── PCB/                      # Printed circuit board designs
    │   └── *.gbr                 # Gerber files for manufacturing
    └── 3D_Models/                # 3D-printed components
        └── *.stl                 # STL files for printing
```

## Hardware Components

### ESP32-Based Control System
- **ESP32-WROOM-32** (240 MHz dual-core)
- **4x Peristaltic pumps** (PWM-controlled, 0-15 ml/h range)
- **LED illumination** with PWM intensity control
- **Power supply:** 12V for pumps, USB for ESP32

### Pump Configuration
1. **Media Pump (Pump 1):** Fresh medium delivery
2. **Signal Pump (Pump 2):** Independent signal/drug injection
3. **Chamber Pump (Pump 3):** Culture delivery (coordinated with media)
4. **Overflow Pump (Pump 4):** Waste removal (3× duration multiplier)

### Flow Coordination Algorithm
- **Synchronized operation:** Media and chamber pumps run simultaneously for T seconds
- **Extended overflow:** Overflow pump continues for 3T seconds
- **Independent signaling:** Signal pump operates on-demand
- **Non-blocking control:** Timer-based operation allows command acceptance during cycles

### GPIO Pin Assignments
```
Pump 1 (Media):     GPIO 25
Pump 2 (Signal):    GPIO 26
Pump 3 (Chamber):   GPIO 27
Pump 4 (Overflow):  GPIO 32
LED Array:          GPIO 33
Status LED:         GPIO 2  (Built-in)
```

## Key Capabilities

### 1. Flow Rate Control
- **PWM Resolution:** 13-bit (8,191 discrete levels)
- **Flow Range:** 0.1-15 ml/min per pump with ±5% accuracy
- **Calibration Model:** Linear relationship: Flow Rate (ml/min) = a × PWM% + b
- **Minimum Flow:** 0.05 ml/h achieved through duty cycling
- **Real-time Adjustment:** Flow rates modifiable during operation

### 2. Experimental Modes

#### Chemostat Mode
- Constant dilution rate with continuous medium supply
- Fixed flow rate independent of cell density
- For steady-state physiology studies

#### Turbidostat Mode
- Constant cell density maintenance through feedback control
- Cell density setpoint (default: 1×10⁶ cells/ml)
- Proportional dilution based on density deviation
- For growth rate measurements and evolutionary experiments

#### Morbidostat Mode (Planned)
- Adaptive drug concentration based on growth response
- Automated drug delivery via signal pump
- For antibiotic resistance evolution studies

### 3. Signal Injection Capabilities

The platform supports precise chemical perturbations:
- **Timed pulses:** User-defined duration and flow rate
- **Signal-pause sequences:** Inject → Mix → Pause protocol
- **Automatic triggering:** Based on cell density thresholds
- **Volume precision:** ±1% accuracy with 0.1 ml minimum delivery

Example signal-pause sequence:
```python
signal_pause(time_s=10, amount_gpm=5, mixing_time_s=30, pause_s=60)
# Injects signal for 10s at 5 g/min
# Mixes for 30s
# Pauses pumps 1&3 for 60s
```

### 4. Research Applications

**Habituation Studies:**
- Attenuation and re-sensitization to repeated non-predictive cues
- Response-decay rate measurements
- Under-lens cue pulses aligned to imaging

**Valence Reassignment:**
- Context-dependent cue value under controlled dilution
- Shifting perceived stimulus value (neutral → aversive/appetitive)

**Threshold Adaptation:**
- Shifts in response onset with changing resource background
- Dynamic chemical and thermal control in situ

**Population Dynamics:**
- Facultative aggregation in *Capsaspora owczarzaki*
- Information sharing via collective behaviors
- Tracking phenotypic exploration and assimilation

## Quick Start

### 1. Hardware Assembly
1. Print 3D components from `Hardware/3D_Models/`
2. Order PCBs using Gerber files from `Hardware/PCB/`
3. Assemble components according to parts list (see `Docs/parts_list.md`)
4. Connect pumps to GPIO pins as specified above

### 2. Firmware Installation
1. Install [Thonny IDE](https://thonny.org/) or similar MicroPython tool
2. Flash MicroPython to ESP32
3. Upload all files from `Firmware/` to ESP32
4. Edit `config.py` with your WiFi credentials (optional for MQTT)

### 3. Pump Calibration
Run the calibration utility to characterize your pumps:
```python
# On ESP32 via Thonny REPL
import local_pump_calibration
local_pump_calibration.run_calibration()
```

This creates CSV calibration files (e.g., `pump1_12V_calib.csv`) with flow-rate vs PWM relationships.

### 4. Basic Operation

**Local Control (No WiFi Required):**
```python
# In Thonny REPL
%Run chemostat_controller.py

# Run chemostat cycle: 15s at specified flow rates (g/min)
>>> chemostat(15, media_flow=10, chamber_flow=10, overflow_flow=30)

# Inject signal: 10s at 5 g/min
>>> signal(10, signal_flow=5)

# Check status
>>> status()

# Stop cycle
>>> stop()
```

**Continuous Operation:**
```python
# Start continuous run with specified flow rates
>>> start(media_flow=10, chamber_flow=10, overflow_flow=30)

# Stop when done
>>> stop()
```

## Advanced Features

### Cellpose Integration (Optional)
For automated turbidostat operation with real-time cell counting:

**Requirements:**
- Python 3.8+ on host computer
- USB microscope camera
- Cellpose library
- MQTT broker (mosquitto)

**Setup:**
```bash
# Install dependencies
pip install opencv-python paho-mqtt cellpose

# Start MQTT broker
mosquitto -v

# Run turbidostat controller
python cellpose_turbidostat.py
```

**Automated Operation:**
1. Camera captures frame every 5 seconds
2. Cellpose analyzes cell count
3. System adjusts dilution to maintain target density
4. Auto-triggers signal injection above threshold

### Signal-Pause Protocol
For experiments requiring chemical perturbation with controlled mixing:

```python
signal_pause(
    time_s=10,          # Signal injection duration
    amount_gpm=5,       # Signal flow rate (g/min)
    mixing_time_s=30,   # Mixing phase duration
    pause_s=60          # Pause duration (pumps 1&3 off)
)
```

**Sequence:**
1. **Inject:** Signal pump delivers compound
2. **Mix:** Media and chamber pumps mix the signal
3. **Pause:** All flow stops for incubation
4. **Resume:** Normal operation continues

### Data Logging
The system automatically logs experimental data:

**ESP32 Local Logging:**
- Creates daily rotating log files
- Records pump states, flow rates, timestamps
- Survives network interruptions

**Log Format:**
```csv
timestamp,pump_id,flow_gpm,duration_s,event_type
2024-01-15 14:30:15,1,10.0,60,CHEMOSTAT_START
2024-01-15 14:30:15,3,10.0,60,CHEMOSTAT_START
2024-01-15 14:30:15,4,30.0,180,OVERFLOW_START
```

## Experimental Design Considerations

### Flow Rate Selection
- **Dilution Rate (D):** D = Flow Rate / Volume
- **Typical Range:** 0.1-1.0 h⁻¹
- **Residence Time:** τ = 1/D
- **Volume:** Standard chamber ~5-10 ml

Example: For a 5 ml chamber with D=0.2 h⁻¹:
- Flow rate = 0.2 × 5 = 1 ml/h
- Residence time = 5 hours

### Signal Injection Timing
- **Minimum Volume:** 0.1 ml (for adequate mixing)
- **Typical Duration:** 5-30 seconds
- **Flow Rate:** 5-10 g/min for aqueous solutions
- **Avoid Washout:** Signal injection should be <10% of cycle time

### Overflow Management
- **3× Multiplier:** Ensures complete evacuation
- **Prevents Backflow:** Extended operation eliminates residual pressure
- **Maintains Volume:** Chamber volume stays constant

## Troubleshooting

### Pump Not Running
1. Check power supply (12V for pumps)
2. Verify GPIO connections
3. Run calibration to confirm pump response
4. Check for MOSFET failure

### Inconsistent Flow Rates
1. Re-run calibration
2. Check tubing for kinks or air bubbles
3. Verify pump orientation (inlet/outlet correct)
4. Clean pump heads if clogged

### WiFi Connection Issues
1. Verify SSID and password in `config.py`
2. Check network range
3. Use serial connection as fallback
4. Restart ESP32

### Cell Count Errors (Cellpose)
1. Adjust camera focus and lighting
2. Calibrate conversion factor in code
3. Check for segmentation artifacts
4. Consider manual counting for validation

## Safety and Maintenance

### Safety Considerations
- **Temperature Limits:** Firmware enforces 42°C cutoff
- **Emergency Stop:** Hardware and software kill switches
- **Current Limiting:** MOSFET circuits prevent pump damage
- **Network Loss:** System continues with last valid schedule

### Maintenance Schedule
- **Daily:** Check pump operation, clean chamber if needed
- **Weekly:** Inspect tubing for wear, verify calibration
- **Monthly:** Full system calibration, backup configuration
- **As Needed:** Replace pump heads, clean electrodes

## Citation

If you use this platform in your research, please cite:

```
Knafo, M., Casacuberta, E., Solé, R., & Ruiz-Trillo, I. (2025). 
Beyond Diffusion: Bayesian Learning Strategies in Single-Cell Life. 
Physical Review E (in preparation).
```

## Documentation

See `Docs/` directory for:
- **MCMC_Software_Spec.md:** Complete software architecture and MQTT topics
- **MCMC_Methods_Materials.tex:** Materials and methods from manuscript
- **MCMClayout.drawio.png:** System wiring diagram
- **parts_list.md:** Bill of materials for hardware assembly

## Support and Contributing

This is an open-source research platform. Contributions welcome!

**Issues:** Report bugs or request features via GitHub issues  
**Documentation:** Improvements to setup guides always appreciated  
**Hardware:** Share your modifications and calibrations  

## License

Open source for research and educational use. See LICENSE file for details.

## Acknowledgments

Developed for studying basal cognition and adaptive behaviors in single-celled organisms. Built on affordable, accessible components to enable widespread adoption in research labs.

---

**Ready for your next experiment!** 🧪🔬

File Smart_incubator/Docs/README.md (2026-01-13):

# Smart Incubator Control System

This repository contains the MicroPython source code for an advanced, automated Smart Incubator. The system is designed to run long-term biological experiments, providing precise temperature control and delivering timed stimuli (like ultrasound and light) according to a configurable scientific protocol.

## Features

- **Precise Temperature Control:** Utilizes a PID controller to manage a PTC heater and a TEC1 cooler, maintaining stable basal temperatures and executing programmed heat shocks.
- **Automated Experiment Cycles:** Runs experiments in cycles of variable length, managing different phases (e.g., basal temperature, heat shock).
- **Configurable Stimuli:** Delivers ultrasound (vibration) and LED light stimuli with configurable timing and intensity.
- **Flexible Protocols:** Supports different experimental protocols by correlating the timing of heat shock and other stimuli in various ways (e.g., stimulus before, during, or after heat shock).
- **Robust Data Logging:** Logs detailed time-series data for each experiment cycle to an SD card, including temperature, setpoints, power levels, and stimuli status. Also saves cycle summaries and experiment metadata.
- **Hardware Abstraction:** Modular code with clear separation between high-level experiment logic, mid-level controllers (temperature, ultrasound), and low-level hardware drivers.
- **Resilience:** Includes mechanisms for error handling, retrying hardware initializations, and recovering from transient sensor or SD card failures to ensure long-term operational stability.
- **Advanced Sensor Recovery:** Automated sensor recovery system that can detect stuck temperature readings and attempt to restore sensor functionality without terminating experiments.
- **Temperature Failsafe Protection:** Comprehensive failsafe system that detects dangerous conditions (stuck sensors, overheating) and automatically protects hardware with progressive response mechanisms.
- **Diagnostic Tools:** Built-in diagnostic systems for comprehensive sensor health monitoring and troubleshooting.
- **Real-time Monitoring:** An OLED display provides real-time feedback on the incubator's status, including current temperature, target temperature, cycle progress, and active stimuli.
- **(Optional) Web Server:** `main_with_server.py` provides an alternative entry point that includes a web server for remote monitoring.

## System Architecture

The Smart Incubator is built on a **sophisticated multi-layer architecture** designed for reliable biological experimentation with precise environmental control. The system follows a modular design pattern with clear separation of concerns across hardware abstraction, control logic, and scientific protocols.

### **Architectural Overview**

```
Application Layer:     main.py → run_experiment_cycle.py
                           ↓
Control Layer:        temp_controller.py → us_control.py
                           ↓
Hardware Layer:       max31865.py → sd_logger.py → oled_display.py
                           ↓
Driver Layer:         heater.py → tec.py → led_control.py → vibration_control.py
                           ↓
Boot Layer:           boot.py (GPIO securing, system initialization)
```

### **Core Components - Detailed Analysis**

#### **1. System Orchestration Layer**

**`main.py` - System Orchestrator & Entry Point**
- **Primary Functions**:
  - **Hardware initialization with retry logic**: 5-attempt initialization sequence with cleanup between attempts
  - **Global parameter management**: Temperature setpoints, timing parameters, correlation modes
  - **Continuous cycle execution**: Infinite loop managing experiment cycles
  - **Error recovery systems**: Consecutive error tracking, automatic restart mechanisms
  - **Memory management**: Garbage collection between cycles, heap monitoring
- **Key Variables**: 
  - `basal_temp = 23.0°C`, `heat_shock_temp = 32.0°C`
  - `min_interval = 200min`, `max_interval = 400min` (cycle length randomization)
  - `correlation = 1` (stimulus-heat shock timing relationship)
- **Error Handling**: Maximum 3 consecutive errors before system halt
- **Memory Optimization**: Explicit garbage collection, global variable cleanup

**`boot.py` - System Initialization & Safety**
- **Critical Safety Features**:
  - **GPIO securing**: All output pins initialized to OFF state on startup
  - **SPI CS management**: Chip select pins set to inactive (HIGH) state
  - **CPU optimization**: 240MHz frequency setting for optimal performance
  - **Memory preparation**: Garbage collection enabled, initial cleanup
  - **Hardware stabilization**: Timed delays for component settling

#### **2. Scientific Protocol Engine**

**`run_experiment_cycle.py` - Experiment Logic Core**
- **Cycle Management**:
  - **Random cycle length**: 200-400 minutes (3.3-6.7 hours) for biological variability
  - **Phase transitions**: Basal temperature maintenance → Heat shock delivery
  - **Correlation-based timing**: 4 different stimulus-heat shock relationships
  - **Real-time monitoring**: 10-second logging intervals throughout cycle
- **Correlation Values** (continuous range -1 to +1):
  - **+1.0**: US always precedes heat shock (paired/predictive) - DEFAULT
  - **0.0**: US delivered at random times (uncorrelated control)
  - **-1.0**: No US delivered (heat shock only control)
  - Intermediate values interpolate between these behaviors
- **Data Collection**:
  - **Snapshot logging**: Temperature, power, mode, phase every 10 seconds
  - **Cycle statistics**: Min/max/average temperatures, error counts, duration
  - **PWM noise mitigation**: Temporary stimulus deactivation during critical temperature logging
- **Error Recovery**: Temperature validation, fallback to last known good values

#### **3. Temperature Regulation System**

**`temp_controller.py` - PID-Based Thermal Control**
- **Advanced PID Implementation**:
  - **Dual-actuator system**: PTC heater (warming) + TEC cooler (cooling)
  - **PID parameters**: kp=6.0, ki=0.02, kd=1.5 (tuned for 1kHz PWM)
  - **Anti-windup protection**: Integral term limiting to prevent overshoot
  - **Target change detection**: PID reset on significant setpoint changes (>2°C)
- **Noise Management**:
  - **PWM interference mitigation**: Coordinated timing between control and measurement
  - **Temperature validation**: Range checking (-50°C to 100°C), spike detection
  - **Multiple reading attempts**: Up to 3 retries with delays for reliable measurement
- **Control Logic**:
  - **Idle zone**: -0.1°C to +0.5°C deadband to prevent actuator oscillation
  - **Heating mode**: Positive PID output → heater activation, cooler OFF
  - **Cooling mode**: Negative PID output → cooler activation + 35% boost, heater OFF
- **Error Handling**: Sensor fault detection, graceful degradation, safety shutdown

#### **4. Hardware Interface Layer**

**`max31865.py` - Precision Temperature Sensing**
- **Advanced Noise Filtering**:
  - **Median filtering**: 5-reading median calculation to eliminate spikes
  - **Change rate limiting**: Maximum 5°C/reading change validation
  - **Historical tracking**: 10-reading history for trend analysis
  - **Multi-attempt reading**: Up to 3 attempts per measurement cycle
- **SPI Communication**:
  - **Bus arbitration**: Coordination with SD card SPI to prevent conflicts
  - **Timing optimization**: 250kHz baudrate, extended delays for reliability
  - **Fault detection**: Real-time MAX31865 fault register monitoring
- **PT100 RTD Processing**:
  - **Resistance calculation**: 430Ω reference resistor compensation
  - **Temperature conversion**: Callendar-Van Dusen equation implementation
  - **Range validation**: 50-200Ω resistance range (≈-50°C to +150°C)

**`sd_logger.py` - Comprehensive Data Management**
- **Structured Data Architecture**:
  - **Experiment directories**: `/sd/data/DDMMYYYY_correlation/`
  - **JSON-based logging**: Individual snapshot files with timestamps
  - **Manifest system**: SHA-256 checksums for data integrity
  - **Metadata preservation**: Complete experiment parameter recording
- **Data Integrity Features**:
  - **Retry mechanisms**: Up to 3 write attempts with delays
  - **Checksum validation**: SHA-256 for all data files
  - **Memory management**: Limited manifest size (100 entries) to prevent memory issues
  - **Error recovery**: Continue operation even if SD logging fails
- **File Organization**:
  - `meta.json`: Experiment parameters and configuration
  - `cycle_N_TIMESTAMP.json`: Individual data snapshots
  - `cycle_N_summary.json`: End-of-cycle statistics
  - `manifest.json`: File integrity and experiment status

**`us_control.py` - Unified Stimulus Management**
- **Multi-Modal Control**:
  - **LED control**: PWM-based brightness (0-100%), default 25%
  - **Vibration control**: PWM-based intensity (0-100%), default 100%
  - **Combined modes**: LED, VIB, or BOTH simultaneously
- **Timing Pattern Management**:
  - **Configurable intervals**: Default 20s ON, 60s OFF for vibration
  - **State tracking**: Real-time activation status monitoring
  - **Synchronized operation**: Coordinated LED/vibration activation
- **Integration Features**:
  - **Temperature-synchronized**: Deactivation during critical temperature readings
  - **Display integration**: Status reporting to OLED display
  - **Error isolation**: Individual component failure handling

**`oled_display.py` - Real-Time Status Interface**
- **Information Display**:
  - **Temperature monitoring**: Current vs. target with 0.1°C precision
  - **Progress tracking**: Visual progress bar, cycle timing
  - **Component status**: US active/inactive, TEC on/off states
  - **Experimental context**: Cycle number, correlation mode display
- **Update Management**:
  - **Rate limiting**: 1-second update intervals to prevent flicker
  - **Error resilience**: Continues operation if display fails
  - **Memory efficient**: Minimal buffer usage for long-term stability

#### **5. Low-Level Hardware Drivers**

**Power Control Modules**:
- **`heater.py`**: PTC heater PWM control (1kHz, 16-bit resolution)
- **`tec.py`**: TEC cooler PWM control with on/off state management
- **`led_control.py`**: LED brightness control (0-100% mapping to 16-bit PWM)
- **`vibration_control.py`**: Vibration motor intensity control with timing patterns

### **Data Flow Architecture**

#### **Initialization Sequence**:
1. **Boot Safety**: GPIO securing, hardware stabilization
2. **Component Init**: Temperature sensor, display, thermal actuators
3. **Storage Setup**: SD card mounting, experiment directory creation
4. **Parameter Loading**: Configuration validation, PID initialization
5. **System Verification**: Initial temperature reading, component status check

#### **Cycle Execution Flow**:
1. **Cycle Planning**: Random duration calculation, correlation-based timing
2. **Temperature Control Loop**: 
   - Continuous PID regulation
   - Real-time power adjustment
   - Noise-mitigated sensor readings
3. **Stimulus Management**:
   - Phase-based activation (basal vs. heat shock periods)
   - Timing pattern execution (vibration intervals)
   - Display status updates
4. **Data Collection**:
   - 10-second snapshot logging
   - Real-time statistics calculation
   - End-of-cycle summary generation
5. **Cycle Completion**: Statistics finalization, cleanup, memory management

#### **Error Recovery Mechanisms**:
- **Temperature Sensor**: Multiple reading attempts, last-valid-value fallback
- **SD Card**: Write retries, continue without logging if persistent failure
- **Display**: Optional component, system continues if initialization fails
- **Power Control**: Safety shutdown on critical errors
- **Memory**: Periodic garbage collection, heap monitoring

### **Inter-Component Communication**

#### **SPI Bus Management**:
- **Shared Resources**: MAX31865 temperature sensor, SD card
- **Arbitration**: Explicit chip select management, timing coordination
- **Noise Prevention**: PWM synchronization, measurement windows

#### **PWM Coordination**:
- **Frequency Standardization**: 1kHz across all PWM channels
- **Interference Mitigation**: Coordinated activation/deactivation
- **Resolution Consistency**: 16-bit duty cycle resolution throughout

#### **State Synchronization**:
- **Global Variables**: Shared component instances across modules
- **Status Propagation**: Real-time state updates to display and logging
- **Error Broadcasting**: Component failure notification system

### Hardware Drivers & Abstractions

- **`heater.py` & `tec.py`**: Advanced PWM-based thermal actuator control with safety features and state management
- **`led_control.py` & `vibration_control.py`**: Low-level stimulus drivers with intensity control and pattern management
- **`max31865.py`**: Sophisticated PT100 RTD sensor driver with noise filtering and fault detection
- **`oled_display.py`**: Real-time status display with rate limiting and error resilience
- **`utils.py`**: Utility functions for random interval generation and JSON handling

### Configuration

The primary experiment parameters are configured at the top of the `main.py` file:

- `basal_temp`: The baseline temperature for the incubator.
- `heat_shock_temp`: The target temperature during the heat shock phase.
- `us_type`: The type of ultrasound stimulus ("LED", "VIB", or "BOTH").
- `min_interval` / `max_interval`: The minimum and maximum duration (in minutes) for a single experiment cycle. The actual length is randomized within this range.
- `us_duration` / `heat_duration`: The duration (in minutes) for the ultrasound stimulus and the heat shock phase.
- `correlation`: A key experimental parameter that defines the timing relationship between the ultrasound stimulus and the heat shock.
    - `0`: Random timing for both.
    - `1`: US immediately precedes the heat shock.
    - `2`: US immediately follows the heat shock.
    - `3`: A special short cycle for testing.

### Data Logging

The `ExperimentLogger` class creates a new directory for each experiment run on the SD card (e.g., `/sd/exp_001`, `/sd/exp_002`, etc.). Each directory contains:

- **`metadata.json`**: A JSON file storing the initial configuration parameters for the experiment.
- **`data.csv`**: A CSV file containing the time-series data for all cycles. Each row is a snapshot with columns for timestamp, cycle number, temperature, setpoint, power, mode, etc.
- **`cycle_summary.csv`**: A CSV file containing a summary for each completed cycle, including min/max/avg temperatures, duration, and error counts.

## How to Run

1.  **Hardware Setup:** Ensure all components (ESP32, temperature sensor, heater, cooler, display, SD card reader) are wired correctly according to the pin definitions in `main.py`.
2.  **Prepare SD Card:** Format an SD card with a FAT32 filesystem. The system will create the necessary files and directories.
3.  **Deploy Code:** Upload all the Python files from the `Smart_incubator` directory to the root of the ESP32's filesystem using a tool like Thonny or `ampy`.
4.  **Power On:** The `boot.py` file will run on startup, and then `main.py` will be executed, starting the initialization process and then the experiment cycles.

The system will print detailed status messages to the serial console (REPL), which is invaluable for monitoring and debugging.

## Hardware Requirements

- ESP32 Development Board
- MAX31865 Temperature Sensor with PT100 RTD
- PTC Heater
- TEC1 Peltier Cooler
- LED Module
- Vibration Module
- SD Card Module (SPI interface)
- SSD1306 OLED Display (128x64, I2C interface)
- MOSFETs for power control

## Pin Assignments

### Power Control
- TEC_PIN: 27 (TEC1 cooler control)
- PTC_PIN: 33 (PTC heater control)
- LED_PIN: 25 (LED control)
- VIB_PIN: 16 (Vibration control)

### SPI (Temperature Sensor & SD Card)
- SCK: 14 (HSPI Clock)
- MOSI: 13 (HSPI MOSI)
- MISO: 12 (HSPI MISO)
- CS_MAX: 5 (MAX31865 Chip Select)
- CS_SD: 15 (SD Card Chip Select)

### I2C (OLED Display)
- SCL: 22 (I2C Clock)
- SDA: 21 (I2C Data)

## SD Card Setup and Requirements

### Critical: SD Card Formatting Requirements

The ESP32 requires a specific SD card format to work reliably:

**Required Format:**
- **File System**: DOS_FAT_32 (not regular FAT32)
- **Partition Scheme**: MBR (Master Boot Record)
- **Size**: 4GB to 32GB recommended

### SD Card Preparation Procedure

#### Option 1: Using the Preparation Script (Recommended)

1. **Format the SD card** properly:
   ```bash
   # On macOS:
   sudo diskutil eraseDisk MS-DOS INCUBATOR MBR /dev/diskX
   
   # On Windows:
   # Use Disk Management to create MBR partition with FAT32
   
   # On Linux:
   sudo fdisk /dev/sdX  # Create MBR partition table
   sudo mkfs.fat -F 32 /dev/sdX1  # Format as FAT32
   ```

2. **Run the preparation script**:
   ```bash
   python prepare_sd_card.py
   ```

3. The script will:
   - Verify the SD card format
   - Create the required `/data/` directory structure
   - Add sample files for testing
   - Verify read/write functionality

#### Option 2: Manual Setup

1. **Format the SD card** as DOS_FAT_32 with MBR partition scheme
2. **Create directory structure**:
   ```
   /
   ├── data/
   │   └── readme.txt (optional test file)
   ```

### SD Card Verification

Use the included diagnostic script to verify your SD card setup:

```python
# Run on ESP32:
import sd_logger
if sd_logger.init_sd():
    print("SD card initialized successfully!")
else:
    print("SD card initialization failed!")
```

### Common SD Card Issues and Solutions

#### Issue: "SD card initialization failed"
**Causes:**
- Incorrect format (needs DOS_FAT_32 with MBR, not GUID)
- Missing `/data/` directory
- Poor SD card quality or corruption
- Loose connections

**Solutions:**
1. Reformat using the correct procedure above
2. Try a different SD card (Class 10 recommended)
3. Check SPI connections (pins 12, 13, 14, 15)

#### Issue: "Data directory creation failed"
**Cause:** SD card is read-only or corrupted

**Solution:** Reformat the SD card completely

#### Issue: Intermittent logging failures
**Causes:**
- Poor quality SD card
- Power supply issues
- SPI interference

**Solutions:**
1. Use a high-quality Class 10 SD card
2. Ensure stable 3.3V power supply
3. Keep SPI wires short and away from power lines

### Data Structure

The system automatically creates the following structure:

```
/sd/data/
├── [experiment_id]/
│   ├── meta.json           # Experiment metadata
│   ├── manifest.json       # File manifest with checksums
│   ├── cycle_X_TIMESTAMP.json  # Data snapshots
│   └── cycle_X_summary.json    # Cycle summaries
```

**Experiment ID Format:** `DDMMYYYY_correlation`
- Based on current date and correlation setting
- Example: `9298_1` (day 9298 since epoch, correlation 1)

## Software Structure

### Core Files
- `main.py`: Main program entry point
- `boot.py`: Boot sequence and initialization
- `temp_controller.py`: Temperature control logic
- `run_experiment_cycle.py`: Experiment cycle management

### Hardware Interfaces
- `max31865.py`: Temperature sensor interface
- `sd_logger.py`: SD card data logging functionality
- `oled_display.py`: OLED display interface
- `ssd1306.py`: SSD1306 OLED driver library

### Control Modules
- `led_control.py`: LED control
- `vibration_control.py`: Vibration control
- `us_control.py`: Unified US (Unconditional Stimulus) controller
- `tec.py`: TEC1 cooler control
- `heater.py`: PTC heater control

### Safety & Diagnostic Modules
- `temperature_failsafe.py`: Advanced failsafe system with stuck sensor detection
- `sensor_recovery.py`: Automated sensor recovery and restoration system
- `sensor_diagnostic.py`: Comprehensive sensor health monitoring and diagnostics

### Utilities
- `prepare_sd_card.py`: SD card preparation script (run on computer)
- `check_files.py`: Verify files are uploaded to ESP32
- `Tests.py`: Hardware test suite

### Documentation
- `BUG_ANALYSIS_AND_SOLUTION.md`: Critical bug analysis and failsafe solution documentation
- `SENSOR_RECOVERY_SOLUTION.md`: Enhanced sensor recovery system documentation
- `README_landscape.md`: Landscape mode experimental protocols
- `landscape_documentation.md`: Advanced landscape executor documentation

## Installation

### 1. Prepare SD Card
Follow the SD card setup procedure above **before** inserting into ESP32.

### 2. Upload Files to ESP32
Ensure all required files are uploaded to your ESP32:

**Required Files:**
- All `.py` files from the project
- Especially: `ssd1306.py` and `oled_display.py` for display
- `sdcard.py` for SD card interface (usually included in MicroPython)

**Verify Upload:**
```python
# Run check_files.py on ESP32 to verify all files are present
import check_files
check_files.check_files()
```

### 3. Hardware Connections
Connect all components according to the pin assignments above.

### 4. Test System
Run the test suite to verify all components:
```python
import Tests
Tests.main()
```

## Usage

### Automatic Operation
1. **Insert prepared SD card** into ESP32
2. **Power on the system**
3. The system will:
   - Initialize all components
   - Create experiment directory
   - Start running cycles with default parameters
   - Log data automatically

### Default Experiment Parameters
- **Basal Temperature**: 23°C
- **Heat Shock Temperature**: 32°C
- **Cycle Duration**: 200-400 minutes (random)
- **US Duration**: 30 seconds
- **Heat Duration**: 30 seconds
- **US Type**: Both LED and vibration
- **Correlation**: 1 (US precedes heat shock)

### Monitoring
- **OLED Display**: Shows real-time status
- **Serial Output**: Detailed logging information
- **SD Card**: All data automatically logged

## Troubleshooting

### Display Issues
- **Check files**: Ensure `ssd1306.py` and `oled_display.py` are uploaded
- **Check connections**: I2C pins 21 (SDA) and 22 (SCL)
- **Check I2C address**: Some displays use 0x3D instead of 0x3C

### Temperature Sensor Issues
- **Check SPI connections**: Pins 5, 12, 13, 14
- **Check RTD connections**: Ensure PT100 is properly connected
- **Check reference resistor**: Should be 430Ω

### Power Issues
- **Ensure adequate power supply**: ESP32 + peripherals need stable 3.3V/5V
- **Check MOSFET connections**: For heater and cooler control

## Data Analysis

Logged data can be analyzed using the included Python scripts:
- Raw JSON files contain detailed measurements
- Manifest files include checksums for data integrity
- Use `plot_data.py` for visualization (run on computer)

## Safety Features

- **Temperature limits**: Automatic shutdown if temperature exceeds safe ranges
- **Watchdog protection**: System resets if frozen
- **Error recovery**: Automatic retry on component failures
- **Data integrity**: Checksums verify logged data

## Support

For issues:
1. Run the test suite (`Tests.py`) to isolate problems
2. Check the SD card setup procedure
3. Verify all files are properly uploaded
4. Check hardware connections

## Contributing

Feel free to submit issues and enhancement requests!

## License

[Your chosen license]

## Author

[Your name/contact information]

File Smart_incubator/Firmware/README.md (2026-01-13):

# Smart Incubator Firmware Directory

## Status: ✅ Fully Implemented

This directory contains the complete firmware for the Smart Incubator Control System v2.0.

## WiFi Configuration Mode (v2.0)

The firmware now includes a **phone-based WiFi setup** mode:

1. **Power on ESP32** → Creates WiFi hotspot `Inc-XXXX`
2. **Connect phone** → Password: `incubator123`
3. **Open browser** → Go to `http://192.168.4.1`
4. **Configure experiment** → Set time, name, correlation, parameters
5. **Press START** → Experiment runs autonomously

## Core Modules

### Main System:
- [x] `main.py` - Main program with WiFi setup and experiment loop
- [x] `boot.py` - Boot configuration and GPIO safety
- [x] `run_experiment_cycle.py` - Experiment cycle execution logic

### WiFi & Configuration:
- [x] `wifi_setup.py` - WiFi Access Point creation (unique SSIDs)
- [x] `experiment_setup_server.py` - Web-based experiment configuration

### Temperature Control:
- [x] `temp_controller.py` - PID temperature controller
- [x] `max31865.py` - PT100 RTD temperature sensor driver
- [x] `heater.py` - PTC heater control
- [x] `tec.py` - TEC cooler control

### Stimuli Control:
- [x] `us_control.py` - Unified stimulus (US) controller
- [x] `led_control.py` - LED PWM control
- [x] `vibration_control.py` - Vibration motor control

### Data & Display:
- [x] `sd_logger.py` - SD card data logging with integrity checks
- [x] `oled_display.py` - OLED status display
- [x] `sdcard.py` - SD card driver
- [x] `ssd1306.py` - OLED display driver

### Safety & Diagnostics:
- [x] `sensor_recovery.py` - Automated sensor recovery
- [x] `temperature_failsafe.py` - Temperature safety protection
- [x] `sensor_diagnostic.py` - Sensor health monitoring
- [x] `max31865_diagnostic.py` - MAX31865 diagnostics

### Utilities:
- [x] `utils.py` - Common utility functions
- [x] `pid_tuning_guide.py` - PID tuning assistance
- [x] `test_deployment.py` - Hardware deployment verification

## Correlation Values

The correlation parameter controls the relationship between the Unconditional Stimulus (US) and heat shock:

| Value | Meaning | Scientific Purpose |
|---|---|---|
| **+1.0** | US always precedes heat shock | Test predictive learning (paired condition) |
| **0.0** | US at random times | Control for temporal association |
| **-1.0** | No US delivered | Heat shock only control |

Intermediate values (e.g., 0.5, -0.5) interpolate between behaviors for graded experiments.

## Deployment

Deploy all firmware files using:

```bash
# Using VS Code (recommended)
Cmd+Shift+B  # or Ctrl+Shift+B on Windows/Linux

# Or command line
python Smart_incubator/sync_firmware.py --yes
```

## Need Help?

- **Architecture:** See `../Docs/MARKOVIAN_HES_FEATURE_OUTLINE.md`
- **Deployment:** See `../DEPLOYMENT_GUIDE.md`
- **Quick start:** See `../QUICK_START.md`

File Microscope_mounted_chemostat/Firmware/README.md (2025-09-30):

# MCMC ESP-C Channel Controller

ESP32-based three-channel chemostat pump and LED controller for the MCMC (Microscope Chemostat) platform.

## 🏗️ Hardware Requirements

### ESP32 Board
- **ESP32 DevKit** (or compatible)
- **Minimum Flash**: 4MB
- **Memory**: 520KB RAM

### Peripherals
- **4x Peristaltic Pumps** (PWM-controlled)
- **1x LED Array** (PWM-controlled)
- **1x Status LED** (visual feedback)
- **1x MicroSD Card** (data logging)
- **WiFi Network** (2.4GHz)

### GPIO Pin Assignments (Default)
```
Pump 1:     GPIO 25
Pump 2:     GPIO 26
Pump 3:     GPIO 27
Pump 4:     GPIO 32
LED:        GPIO 33
Status LED: GPIO 2
SD Card:    SPI (see config.py)
```

## 🚀 Quick Start

### 1. Configure Channel
Edit `config.py` for your specific channel:
```python
CHANNEL_ID = 1  # Change to 2 or 3 for other channels
```

### 2. Network Setup
```python
WIFI_SSID = "YourNetworkName"
WIFI_PASSWORD = "YourPassword"
MQTT_BROKER = "192.168.1.100"
```

### 3. Deploy to ESP32
```bash
# Copy all files to ESP32
ampy put config.py
ampy put boot.py
ampy put main.py
ampy put esp_c_controller.py
ampy put Hardware_modules/
```

### 4. Monitor Operation
```bash
# Watch serial output
screen /dev/ttyUSB0 115200
```

## 📊 System Architecture

### Control Loop (1Hz)
```
WiFi Check → MQTT Process → Pump Updates → LED Updates → Status Report → Logging
```

### Command Queuing
- **FIFO Queue**: Up to 5 commands per pump
- **Duration Limit**: 1 hour max per command
- **Real-time Volume**: Continuous tracking with calibration

### Safety Systems
- **Hardware Watchdog**: 8-second timeout
- **MQTT Timeout**: 60-second failsafe with LED indication
- **Emergency Stop**: Immediate shutdown on `cmd/kill`
- **Parameter Validation**: Duty (0-100%), duration (0-3600s)

## 🔧 Enhanced Features

### PWM Compatibility
```python
# Handles both 10-bit and 16-bit MicroPython builds
if hasattr(self.pwm, "duty_u16"):
    self.pwm.duty_u16(pwm_val << 6)  # 16-bit
else:
    self.pwm.duty(pwm_val)           # 10-bit
```

### Calibration Management
```python
# Direct float storage for performance
ml_per_hour = (self.calib_a * duty_percent) + self.calib_b

# Zero coefficient warning
if self.calib_a == 0.0:
    print("WARNING: Pump may be stalled")
```

### Volume Tracking Precision
```python
# Proper tick handling prevents wraparound
elapsed_ms = utime.ticks_diff(utime.ticks_ms(), self.start_time)
volume = self.calculate_volume(duty, elapsed_ms / 1000.0)
```

## 📡 MQTT Protocol

### Command Topics
```
cmd/chan{N}/pump{1-4}   - Individual pump control
cmd/chan{N}/led         - LED control
cmd/chan{N}/calibrate   - Update calibration coefficients
cmd/chan{N}/flush       - Clear command queues
cmd/chan{N}/reset_volumes - Reset volume counters
cmd/kill                - Emergency stop (all channels)
```

### Status Topic
```
stat/chan{N}            - Channel status and telemetry
```

### Command Examples

#### Pump Control
```json
# cmd/chan1/pump2
{
  "duty": 75.5,
  "dur": 300
}
```

#### LED Control
```json
# cmd/chan1/led
{
  "duty": 50.0,
  "dur": 60
}
```

#### Calibration Update
```json
# cmd/chan1/calibrate
{
  "pump1": {"a": 2.5, "b": 0.1},
  "pump2": {"a": 2.7, "b": -0.05}
}
```

#### Queue Management
```json
# cmd/chan1/flush (specific pumps)
{
  "pumps": [1, 3]
}

# cmd/chan1/flush (all pumps)
{}
```

#### Volume Reset
```json
# cmd/chan1/reset_volumes (specific pumps)
{
  "pumps": [2, 4]
}

# cmd/chan1/reset_volumes (all pumps)
{}
```

### Status Response
```json
{
  "pump_duty": [0, 75.5, 0, 0],
  "led_duty": 50.0,
  "queued": 3,
  "total_volume": [0.0, 45.2, 0.0, 0.0],
  "active_pump": 2,
  "uptime": 3600,
  "mqtt_timeout": false,
  "emergency_stop": false
}
```

## 💾 Data Logging

### CSV Format
```
Timestamp,Pump,Duty,Duration,LED_Duty,Volume,CommandID,Event
2024-01-15 14:30:15,2,75.5,300,0,45.234,cmd_1_12345,PUMP_CMD
2024-01-15 14:35:20,0,0,0,50.0,0.0,cmd_1_12380,LED_CMD
```

### Log Rotation
- **Daily Rotation**: New file each day
- **Filename Format**: `chan{N}_log_YYYYMMDD.csv`
- **Auto-header**: CSV header added to new files
- **Hot Insert**: SD card detection after boot

## ⚠️ Safety Features

### Emergency Stop Sequence
1. **Immediate PWM shutdown** for all pumps/LED
2. **Queue clearing** (all pending commands)
3. **PWM deinit** for clean restart
4. **Fast LED blink** (emergency indication)
5. **MQTT notification** via status report

### MQTT Timeout Handling
```python
# 60-second timeout detection
if utime.ticks_diff(now, last_mqtt) > 60000:
    emergency_shutdown()
    led_mode = "timeout"  # Fast blink indication
```

### Parameter Validation
```python
# Early rejection of invalid commands
if duty_percent == 0 or duration_sec == 0:
    return False  # Don't waste queue slots

# Strict bounds checking  
duty = max(0, min(100, duty_percent))
duration = max(0, min(3600, duration_sec))
```

## 🛠️ Advanced Configuration

### Debug Mode
```python
# Enable verbose logging
pump_bank = PumpBank(PUMP_PINS, calibrations, debug=True)
led_controller = QueuedLEDController(LED_PIN, debug=True)
```

### PWM Frequency Adjustment
```python
# Quieter operation at higher frequency
pump.set_frequency(2000)  # 2kHz instead of 1kHz
```

### Calibration Validation
```python
# Check for stalled pumps
if pump.calib_a == 0.0:
    print("WARNING: Zero flow coefficient detected")
```

## 📈 Performance Optimizations

### Memory Efficiency
- **Direct float storage**: Avoid dict lookups in control loops
- **Garbage collection**: Managed collection timing
- **String interning**: Reuse common strings

### Timing Precision
- **Tick arithmetic**: Proper wraparound handling
- **Async control**: Non-blocking operation
- **Hardware watchdog**: System reliability

### Network Resilience
- **Exponential backoff**: WiFi reconnection (1s → 60s)
- **MQTT keepalive**: 30-second heartbeat
- **QoS=1**: Critical message delivery

## 🐛 Troubleshooting

### Common Issues

#### WiFi Connection Failed
```
[WiFi] Connection failed! Next retry in 2s
```
**Solution**: Check SSID/password, signal strength

#### MQTT Timeout
```
[MQTT] Timeout detected - emergency shutdown
```
**Solution**: Check broker connectivity, firewall rules

#### SD Card Error
```
[SD] Initialization failed: no SD card
```
**Solution**: Insert formatted SD card, check wiring

#### Queue Full
```
[Pump1] Command rejected (queue full)
```
**Solution**: Reduce command rate or flush queue

### LED Status Indicators

| Pattern | Meaning |
|---|---|
| Solid ON | Normal operation |
| Slow blink (1Hz) | WiFi/MQTT connecting |
| Fast blink (5Hz) | MQTT timeout |
| Very fast blink (10Hz) | Emergency stop |

### Serial Debugging
```python
# Enable debug output for all components
CONTROL_DEBUG = True
```

## 🔧 Hardware Assembly

### Pump Connections
```
ESP32 GPIO → Driver Board → Pump
   25    →    PWM1      →  Pump 1
   26    →    PWM2      →  Pump 2  
   27    →    PWM3      →  Pump 3
   32    →    PWM4      →  Pump 4
```

### Power Requirements
- **ESP32**: 5V/1A via USB or VIN
- **Pumps**: 12V/2A (external supply)
- **LED**: 12V/500mA (shared with pumps)

### Recommended Driver
- **Motor Driver**: TB6612FNG or L298N
- **PWM Input**: 3.3V compatible
- **Frequency**: 1-3 kHz optimal

## 📚 API Reference

### PumpController Class
```python
pump = PumpController(pin=25, pump_id=1, calibration={"a": 2.5, "b": 0.0})

# Control methods
pump.start(duty_percent, duration_sec)
pump.stop()
pump.set_duty(duty_percent)
pump.set_frequency(frequency)

# Calibration
pump.set_calibration(a, b)
pump.get_calibration()

# Status
status = pump.get_status()
volume_rate = pump.get_current_volume_rate()

# Safety
pump.emergency_stop()
pump.reset_volume()
```

### PumpBank Class
```python
bank = PumpBank(pump_pins=[25,26,27,32], calibrations=None, debug=False)

# Command queuing
bank.queue_command(pump_id, duty, duration, command_id, max_queue=5)
bank.flush_queue(pump_id)
bank.flush_all_queues()

# Management
bank.update_all()
bank.get_all_status()
bank.emergency_stop_all()
bank.update_calibration(calibrations)
bank.reset_volumes(pump_ids=None)
```

### QueuedLEDController Class
```python
led = QueuedLEDController(pin=33, debug=False)

# Control
led.queue_command(duty, duration, command_id)
led.set_duty(duty)
led.stop()

# Status
status = led.get_status()
led.emergency_stop()
```

## 🔄 Integration with Host

### Python Host Example
```python
import paho.mqtt.client as mqtt
import json

def send_pump_command(channel, pump, duty, duration):
    topic = f"cmd/chan{channel}/pump{pump}"
    payload = {"duty": duty, "dur": duration}
    client.publish(topic, json.dumps(payload))

def handle_status(client, userdata, msg):
    if msg.topic.startswith("stat/chan"):
        status = json.loads(msg.payload)
        print(f"Active pump: {status['active_pump']}")
        print(f"Total volume: {status['total_volume']}")

client = mqtt.Client()
client.on_message = handle_status
client.connect("192.168.1.100", 1883, 60)
client.subscribe("stat/chan+")
```

## 📋 System Specifications

| Parameter | Value | Notes |
|---|---|---|
| Control Frequency | 1.0 Hz | Fixed per specification |
| Max Command Duration | 3600 s | 1 hour safety limit |
| Queue Depth | 5 commands | Per pump |
| PWM Frequency | 1 kHz | Configurable 1-3 kHz |
| PWM Resolution | 10-bit (1023) | ESP32 default |
| Volume Precision | ±5% | With proper calibration |
| MQTT Timeout | 60 s | Configurable |
| Watchdog Timeout | 8 s | Hardware failsafe |
| Log Rotation | Daily | Automatic |

---

## 📄 License

Part of the MCMC (Microscope Chemostat) project. See main project license.

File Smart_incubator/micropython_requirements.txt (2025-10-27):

# MicroPython Packages Required for Smart Incubator
# These will be installed automatically on first deployment

# Display driver (if using SSD1306 OLED)
# micropython-ssd1306

# Temperature sensor (if using MAX31865)
# micropython-max31865

# Add your required packages here, one per line
# Format: package-name
# Example:
# micropython-umqtt.simple
# micropython-urequests

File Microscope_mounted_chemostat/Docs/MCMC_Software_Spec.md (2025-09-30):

# MCMC Microscope Chemostat – Software Specification

## 0 Goal
Create a full control‑and‑analysis stack that converts a standard microscope into an automated three‑channel chemostat platform.

* Drive **12 pumps**, **3 LED pairs**, and **TEC + PTC** via four Wi‑Fi‑connected ESP32 nodes.  
* Close the loop in four culture modes—**chemostat, turbidostat, morbidostat, aggregation‑stat**—using real‑time cell counts from Cellpose segmentation of microscope TIFFs.  
* Maintain sample temperature at a user‑defined set‑point within **±0.5 °C** with PID control and a hard safety cutoff at **42 °C**.  
* Offer a lightweight GUI for live plots, on‑the‑fly parameter edits, and an emergency kill switch.  
* Persist all raw and derived data in a structured run folder for reproducible experiments.

---

## 1 Hardware / Firmware Layout

| Node | Language | I/O | Responsibilities |
|---|---|-----|---|
| **ESP‑T** (1×) | MicroPython | 2 PWM (TEC & PTC), 1 ADC (PT100) | PID @ 1 Hz, temperature logging to SD |
| **ESP‑C1/2/3** (3×) | MicroPython | 4 PWM pumps + 1 PWM LED each | Mode execution, SD fallback logging |

* All nodes connect over **802.11 n** to an MQTT broker running on the Mac host.  
* Each ESP keeps a 24 h rolling log on its onboard SD card (temperature for ESP‑T, channel stats for ESP‑C\*).

### ESP-T Implementation Details

**✅ COMPLETED** - The ESP-T temperature controller has been fully implemented with the following features:

* **Hardware Interface**: MAX31865 + PT100 sensor, PTC heater (GPIO 33), TEC cooler (GPIO 27)
* **PID Controller**: Asymmetric gains (heating: 1.0, cooling: 1.35) with anti-windup
* **Safety Systems**: 42°C hard cutoff, emergency kill switch, sensor fault detection
* **Communication**: MQTT over WiFi with automatic reconnection
* **Data Logging**: Daily rotating CSV logs on SD card with timestamp precision
* **Status Indication**: LED feedback for heating/cooling/idle/emergency states
* **Configuration**: Externalized settings in `config.py` for easy deployment

**File Structure**:
```
ESP_T_Module/
├── boot.py                 # ESP32 boot configuration
├── main.py                 # Entry point with error handling
├── config.py               # Configuration settings
├── esp_t_controller.py     # Main temperature controller
├── README.md               # Setup and operation guide
└── Temp_aux_scripts/
    ├── temp_controller.py  # PID controller with asymmetric dead-band
    ├── heater.py           # PTC heater PWM control
    ├── tec.py              # TEC cooler PWM control
    └── max31865.py         # PT100 sensor interface
```

---

## 2 Host Stack (Mac, Python‑only)

```text
mosquitto               # MQTT broker (no auth) - ✅ READY
controller/             # asyncio service - 🔄 PENDING
 ├─ calibration.py      # ml h⁻¹ ↔ PWM (±5 %)
 ├─ modes/
 │   ├─ chemostat.py    # constant D  (table TBD)
 │   ├─ turbidostat.py  # cell‑count set‑point (TBD)
 │   ├─ morbidostat.py  # user‑supplied drug rule
 │   └─ aggstat.py      # cluster‑size trigger
 ├─ imaging_watch.py    # watches IMG/ for *.tif
 │   └─ cellpose_wrap.py
gui.py                  # PyQt/PySide minimal GUI - 🔄 PENDING
```

*Cellpose* must fall back to CPU if no GPU is present; auto‑detect at runtime.

---

## 3 MQTT Contract

| Topic | JSON Payload | Description |
|---|---|---|
| `cmd/chan{n}/pump{m}` | `{ "duty": 0‑100, "dur": s }` | Start pump *m* on channel *n* |
| `cmd/chan{n}/led` | `{ "duty": 0‑100, "dur": s }` | Drive LED pair on channel *n* |
| `cmd/temp` | `{ "setpoint": °C }` | Update PID target - **✅ IMPLEMENTED** |
| `cmd/kill` | `{}` | Immediate global PWM = 0 - **✅ IMPLEMENTED** |
| `stat/temp` | `{ "T": °C, "TEC_PWM": %, "PTC_PWM": %, "setpoint": °C, "mode": "string", "safety_shutdown": bool }` | 1 Hz temperature telemetry - **✅ IMPLEMENTED** |
| `stat/chan{n}` | `{ "pump_duty": [%, …], "led_duty": % }` | 1 Hz channel telemetry |

No authentication for now. One **`cmd/kill`** message halts all actuators.

### Temperature Control MQTT Examples

**Set temperature to 25°C**:
```bash
mosquitto_pub -h localhost -t "cmd/temp" -m '{"setpoint": 25.0}'
```

**Emergency stop**:
```bash
mosquitto_pub -h localhost -t "cmd/kill" -m '{}'
```

**Monitor temperature status**:
```bash
mosquitto_sub -h localhost -t "stat/temp"
# Example output:
# {"T": 24.85, "TEC_PWM": 0, "PTC_PWM": 12.3, "setpoint": 25.0, "mode": "Heating", "safety_shutdown": false}
```

---

## 4 Data Layout

```text
run_YYYYMMDD/
 ├── Temp/          temp_log_YYYYMMDD.csv - ✅ IMPLEMENTED
 ├── IMG/           ch{n}_YYYYMMDD_HHMMSS.tif
 │                  ch{n}_YYYYMMDD_HHMMSS_seg.npy
 └── CSV_AGG/       ch{n}_YYYYMMDD.csv   # timestamp, channel, cell_count,
                                         # mean_size, live_pct, dead_pct
```

* A new aggregation CSV opens every 24 h.  
* All raw TIFFs and logs are kept indefinitely.

### Temperature Log Format - ✅ IMPLEMENTED

ESP-T automatically creates daily rotating temperature logs:

**File**: `/sd/temp_log_YYYYMMDD.csv`  
**Columns**: `timestamp,temp_c,setpoint_c,heater_pwm,cooler_pwm,mode`  
**Example**:
```csv
timestamp,temp_c,setpoint_c,heater_pwm,cooler_pwm,mode
2024-06-12 14:30:15,23.45,23.0,15.2,0,Heating
2024-06-12 14:30:16,23.48,23.0,12.1,0,Heating
2024-06-12 14:30:17,23.52,23.0,0,0,Idle
```

---

## 5 Calibration & Maintenance

* **Pump auto‑calibration** – Host issues a stepped PWM profile, weighs output, fits a linear ml h⁻¹ ↔ PWM curve (≤ 5 % error). Constants sent to each ESP at run start.  
* **PID gains** – Set manually or by an optional auto‑tune wizard. **✅ ESP-T defaults: Kp=18.0, Ki=0.1, Kd=0.0**
* **Firmware & analysis versioning** – GitHub repo with semantic tags; CI pipeline TBD.  

### Temperature Calibration - ✅ IMPLEMENTED

The ESP-T system includes built-in calibration features:

* **Sensor Validation**: PT100 + MAX31865 provides ±0.01°C resolution with built-in fault detection
* **Asymmetric Control**: Separate heating (1.0) and cooling (1.35) gains for optimal performance
* **Dead-band Tuning**: 0.2°C heating threshold, 0.5°C cooling threshold
* **Safety Verification**: Hard 42°C cutoff with <1 second response time

**PID Tuning Parameters** (in `ESP_T_Module/config.py`):
```python
PID_KP = 18.0               # Proportional gain
PID_KI = 0.1                # Integral gain  
PID_KD = 0.0                # Derivative gain
HEATING_GAIN = 1.0          # Heating output scaling
COOLING_GAIN = 1.35         # Cooling output scaling
```

---

## 6 Implementation Status

### ✅ Completed Components

* **ESP-T Temperature Controller**: Full implementation with PID control, MQTT, safety systems, and SD logging
* **Temperature Sensor Interface**: MAX31865 + PT100 with fault detection and retry logic
* **Actuator Control**: PTC heater and TEC cooler with PWM control and asymmetric gains
* **Safety Systems**: 42°C hard cutoff, emergency kill switch, network loss handling
* **Data Logging**: 24-hour rotating CSV logs with configurable format
* **Configuration Management**: Externalized settings for easy deployment and tuning

### 🔄 Pending Implementation

* **ESP-C1/2/3 Controllers**: Pump and LED control nodes (similar architecture to ESP-T)
* **Host Python Controller**: asyncio service for coordinating all nodes
* **Mode Implementations**: Chemostat, turbidostat, morbidostat, aggregation-stat control algorithms
* **Cellpose Integration**: Real-time cell counting and segmentation
* **GUI Application**: PyQt/PySide interface for monitoring and control
* **Pump Calibration System**: Automated flow rate characterization

### 📋 Next Development Steps

1. **ESP-C Channel Controllers**: Adapt ESP-T architecture for pump/LED control
2. **Host MQTT Broker Setup**: Configure mosquitto on Mac with proper topics
3. **Python Controller Framework**: asyncio service with mode scheduling
4. **Basic GUI**: Temperature monitoring and setpoint control interface
5. **Pump Calibration**: Automated characterization and linearization
6. **Integration Testing**: Full system validation with all nodes

---

## 7 Open Items (to specify later)

* Chemostat dilution‑rate table.  
* Turbidostat set‑point and hysteresis band.  
* Morbidostat drug‑adjust algorithm.  
* Aggregation‑stat cluster‑size threshold.  
* ~~Final PID Kp/Ki/Kd values~~ - **✅ IMPLEMENTED** (Kp=18.0, Ki=0.1, Kd=0.0)
* Minimum GPU spec (if any).  
* Optional flow‑sensor integration.  
* Depth of CI/testing pipeline.
* ESP-C pump/LED controller pin assignments and protocols
* Host-side data aggregation and analysis pipeline
* GUI design and user workflow specifications

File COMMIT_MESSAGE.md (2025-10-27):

# Git Commit Message

## Short Version (for commit title):
```
Fix: Add critical SD card and temperature sensor failure handling
```

## Detailed Version (for commit body):
```
Fix: Add critical SD card and temperature sensor failure handling

Problem Analysis:
- Experiment failed after cycle 8 but displayed cycle 48 on screen
- SD card silently stopped writing data without halting experiment
- Memory buildup from unsaved manifest entries (1800+ per cycle)
- Temperature sensor eventually failed due to resource exhaustion
- Poor experiment ID generation (always "0_0")

Critical Fixes:
1. SD Card Failure Detection
   - Track consecutive write failures (max 10)
   - Mark SD as unhealthy and halt experiment when threshold exceeded
   - Check SD health before each cycle starts
   - Proper error propagation to stop entire experiment

2. Temperature Sensor Robustness
   - Raise exceptions on critical sensor failures (stops experiment)
   - Increased error threshold from 5 to 10 (more tolerant)
   - Gradual error recovery (decrement vs immediate reset)
   - Better fault detection and reporting with MAX31865 codes

3. Memory Management
   - Reduced manifest file list from 100 to 50 entries
   - Added pre-cycle memory monitoring
   - Warning when free memory < 10KB

4. Experiment ID Generation
   - Changed from timestamp/86400 to YYYYMMDD_HHMMSS_corr format
   - Uses RTC when available, falls back to Unix timestamp
   - More readable and prevents ID collisions

5. Error Handling Improvements
   - All critical failures now raise exceptions
   - Clear error severity levels: [INFO], [WARNING], [ERROR], [CRITICAL]
   - Proper experiment finalization on failures
   - Detailed error messages with failure counts

Files Modified:
- sd_logger.py: Failure tracking, better ID generation, memory limits
- run_experiment_cycle.py: SD health checks, temperature error propagation
- main.py: Pre-cycle health checks, memory monitoring
- temp_controller.py: Gradual error recovery, increased tolerance

Documentation Added:
- EXPERIMENT_FAILURE_ANALYSIS.md: Root cause analysis and fixes
- TEMPERATURE_SENSOR_ROBUSTNESS.md: Detailed error handling guide

Result:
System now fails safely and loudly rather than running blind with data loss.
Both SD card and temperature sensor failures halt experiments immediately.
```

## One-liner for quick commits:
```
Fix critical silent failures in SD logging and temperature sensing that caused experiment to run 40+ cycles without saving data
```

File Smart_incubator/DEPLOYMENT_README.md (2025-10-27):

# Smart Incubator - Deployment Summary

## 🚀 Quick Start

### Brand New ESP32?
```bash
python3 Smart_incubator/sync_firmware.py
```
That's it! The script will automatically:
- ✅ Install required MicroPython packages
- ✅ Create SD card directories
- ✅ Upload all firmware files
- ✅ Upload all config files

### Already Set Up?
```bash
# In VS Code, just press:
Cmd+Shift+B

# Or run:
python3 Smart_incubator/sync_firmware.py
```
Only uploads changed files - takes 3-5 seconds!

---

## 📚 Documentation

- **[QUICK_START.md](QUICK_START.md)** - Visual workflow guide with diagrams
- **[DEPLOYMENT_GUIDE.md](DEPLOYMENT_GUIDE.md)** - Complete reference manual

---

## 🛠️ Installation (One-Time)

```bash
pip install mpremote esptool adafruit-ampy rshell
```

---

## 📁 Files Created

- **`sync_firmware.py`** - Smart sync script (auto-detects changes)
- **`deploy.sh`** - Manual deployment script with modes
- **`micropython_requirements.txt`** - MicroPython packages to install
- **`.deployment_cache.json`** - Tracks uploaded files (auto-created)
- **`.esp32_initialized`** - Marks ESP32 as set up (auto-created)
- **`.vscode/tasks.json`** - VS Code one-click tasks

---

## ⚡ Usage Examples

### Deploy to blank ESP32:
```bash
python3 Smart_incubator/sync_firmware.py
```

### Daily development:
```bash
# Edit files → Press Cmd+Shift+B → Done!
```

### Update single file:
```bash
mpremote connect /dev/tty.usbserial-0001 cp Firmware/main.py :/main.py
```

### Force reinstall everything:
```bash
python3 Smart_incubator/sync_firmware.py --force
```

### Open Python REPL on ESP32:
```bash
mpremote connect /dev/tty.usbserial-0001 repl
```

---

## 🎯 Why This is Better Than Thonny

| Feature | Thonny (Old) | Smart Sync (New) |
|---|---|---|
| **Speed** | 5-10 min | 3-5 sec |
| **Manual steps** | 15-20 copy-pastes | 1 keystroke |
| **Track changes** | Manual | Automatic |
| **First setup** | Tedious | Automated |
| **Error-prone** | High | None |
| **Bulk updates** | Painful | Instant |

**Result: 50-100x faster!** ⚡

---

## 🎓 Common Tasks

| Task | Method |
|---|---|
| Update firmware | Press `Cmd+Shift+B` in VS Code |
| Start experiment | VS Code → "Tasks: Run Task" → "Run Experiment" |
| Debug on device | VS Code → "Tasks: Run Task" → "Open REPL" |
| Check files on ESP32 | `mpremote connect PORT ls` |
| Add MicroPython package | Edit `micropython_requirements.txt`, re-sync |

---

## 🆘 Troubleshooting

**Problem:** Port not found
```bash
ls /dev/tty.*  # Find your port
```

**Problem:** Upload fails
```bash
mpremote connect PORT reset  # Reset first, then retry
```

**Problem:** Files not updating
```bash
python3 Smart_incubator/sync_firmware.py --force
```

**Problem:** Need to start over
```bash
rm .deployment_cache.json .esp32_initialized
python3 Smart_incubator/sync_firmware.py
```

---

## 📖 Next Steps

1. **Read:** [QUICK_START.md](QUICK_START.md) for visual workflow
2. **Reference:** [DEPLOYMENT_GUIDE.md](DEPLOYMENT_GUIDE.md) for details
3. **Start coding:** Press `Cmd+Shift+B` to deploy!

**Happy coding! 🚀**

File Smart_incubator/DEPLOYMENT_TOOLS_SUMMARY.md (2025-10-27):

# Smart Incubator Deployment Tools Summary

Quick reference for all deployment tools and shortcuts.

---

## 🚀 Quick Commands

| What You Want | Command | Shortcut |
|---|---|---|
| **Deploy firmware changes** | `python3 Smart_incubator/sync_firmware.py` | `Cmd+Shift+B` |
| **Format SD (via ESP32)** | `python3 Smart_incubator/format_sd_card.py` | `Cmd+Shift+P` → Format SD Card |
| **Format SD (local reader)** | `python3 Smart_incubator/format_sd_card_local.py /dev/diskX` | - |
| **List local disks** | `python3 Smart_incubator/format_sd_card_local.py --list` | - |
| **Force full reinstall** | `python3 Smart_incubator/sync_firmware.py --force` | - |
| **Open REPL** | `mpremote connect PORT repl` | `Cmd+Shift+P` → Open REPL |
| **List files** | `mpremote connect PORT ls` | `Cmd+Shift+P` → List Files |
| **Reset device** | `mpremote connect PORT reset` | `Cmd+Shift+P` → Reset Device |

---

## 📦 Available Tools

### 1. Intelligent Sync (`sync_firmware.py`)
**Auto-detects changes and only uploads modified files**

```bash
# First time (blank ESP32)
python3 Smart_incubator/sync_firmware.py
# → Installs packages, creates dirs, uploads everything

# Subsequent runs
python3 Smart_incubator/sync_firmware.py
# → Only uploads changed files (fast!)

# Force complete reinstall
python3 Smart_incubator/sync_firmware.py --force
```

**Features:**
- ✅ Auto-detects ESP32 port
- ✅ Tracks file changes via SHA-256 hashing
- ✅ Handles blank ESP32 automatically
- ✅ Installs MicroPython packages from requirements
- ✅ Creates SD card directory structure
- ✅ Smart caching for fast deployments

---

### 2. SD Card Formatter - Two Options

#### Option A: Format via ESP32 (`format_sd_card.py`)
**For SD cards already in the ESP32**

```bash
# Auto-detect ESP32 port
python3 Smart_incubator/format_sd_card.py

# Specify port
python3 Smart_incubator/format_sd_card.py /dev/tty.usbserial-0001
```

**What it does:**
1. 🗑️ Removes `/sd/data/*` (all experiments)
2. 🗑️ Removes `/sd/*.json` (all configs)
3. 📁 Creates `/sd/data/markovian_experiments/`
4. 📁 Creates `/sd/configs_backup/`
5. 📊 Shows storage statistics

**When to use:**
- SD card is already in ESP32
- Quick cleanup between experiments
- Remote formatting

#### Option B: Format Locally (`format_sd_card_local.py`)
**For SD cards in your computer's SD reader**

```bash
# List available disks
python3 Smart_incubator/format_sd_card_local.py --list

# Format specific disk (macOS)
python3 Smart_incubator/format_sd_card_local.py /dev/disk4

# Format specific disk (Linux)
python3 Smart_incubator/format_sd_card_local.py /dev/sdb
```

**⚠️ WARNING: Completely erases and reformats the SD card!**

**What it does:**
1. 💾 Formats as FAT32 (DOS_FAT_32) with MBR
2. 📁 Creates `/data/markovian_experiments/`
3. 📁 Creates `/configs_backup/`
4. 📊 Shows storage statistics

**When to use:**
- Brand new SD card
- SD card needs complete reformat
- File system corruption
- Want guaranteed clean slate

**Safety features:**
- Requires typing "YES" to confirm
- Shows disk info before formatting
- Verifies disk is removable media
- Won't format system disks

---

### 3. Manual Deploy Script (`deploy.sh`)
**Traditional deployment for specific scenarios**

```bash
# Core HES modules only
./Smart_incubator/deploy.sh /dev/tty.usbserial-0001 core

# Full firmware
./Smart_incubator/deploy.sh /dev/tty.usbserial-0001 full

# Config files only
./Smart_incubator/deploy.sh /dev/tty.usbserial-0001 config-only
```

---

## 🎯 VS Code Tasks

**Press `Cmd+Shift+P` → "Tasks: Run Task" → Choose:**

| Task | What It Does | When to Use |
|---|---|---|
| **Sync Firmware (Auto)** ⭐ | Smart sync (only changed files) | Daily development |
| **Format SD Card** | Clean SD card structure | Start new experiments |
| **Deploy Core HES Modules** | Upload HES system files | Testing HES changes |
| **Deploy Full Firmware** | Upload everything | Major updates |
| **Deploy Config Files Only** | Upload JSON configs | Tweak parameters |
| **Open REPL** | Interactive Python shell | Testing/debugging |
| **Run Experiment** | Start experiment | Launch experiments |
| **List Files on Device** | Show filesystem | Check what's deployed |
| **Reset Device** | Soft reset ESP32 | Apply changes |

**Default Task:** `Cmd+Shift+B` runs "Sync Firmware (Auto)"

---

## 📋 Typical Workflows

### New ESP32 Setup
```bash
1. Flash MicroPython (one time)
   esptool.py --port PORT erase_flash
   esptool.py --port PORT write_flash -z 0x1000 firmware.bin

2. Initial deployment
   python3 Smart_incubator/sync_firmware.py
   # Will auto-detect it's first time and do full setup

3. Format SD card
   python3 Smart_incubator/format_sd_card.py

4. Test
   mpremote connect PORT repl
   >>> import markovian_hes_executor
```

### Daily Development
```bash
1. Edit code in VS Code

2. Press Cmd+Shift+B
   # Auto-syncs only changed files

3. Test in REPL
   Press Cmd+Shift+P → "Tasks: Run Task" → "Open REPL"
```

### Start New Experiment Series
```bash
1. Format SD card
   python3 Smart_incubator/format_sd_card.py
   # Type YES twice to confirm

2. Deploy new configs
   python3 Smart_incubator/sync_firmware.py
   # Or use "Deploy Config Files Only" task

3. Run experiment
   Press Cmd+Shift+P → "Tasks: Run Task" → "Run Experiment"
```

### Troubleshooting/Reset
```bash
1. Force complete reinstall
   python3 Smart_incubator/sync_firmware.py --force

2. Format SD card
   python3 Smart_incubator/format_sd_card.py

3. Reset device
   Press Cmd+Shift+P → "Tasks: Run Task" → "Reset Device"
```

---

## 🔧 Direct mpremote Commands

For quick one-off operations:

```bash
# Upload single file
mpremote connect PORT cp local.py :/remote.py

# Upload to SD card
mpremote connect PORT cp config.json :/sd/config.json

# List root files
mpremote connect PORT ls

# List SD card
mpremote connect PORT ls /sd

# Execute command
mpremote connect PORT exec "print('Hello ESP32!')"

# Run script without uploading
mpremote connect PORT run test.py

# Reset
mpremote connect PORT reset

# Mount filesystem (amazing for development!)
mpremote connect PORT mount Smart_incubator/Firmware
# Now files run from YOUR computer!
```

---

## 🆘 Troubleshooting

### Port Not Found
```bash
# Check connection
ls /dev/tty.*          # macOS
ls /dev/ttyUSB*        # Linux
mode                   # Windows

# Manual port specification
python3 Smart_incubator/sync_firmware.py /dev/tty.usbserial-0001
```

### Permission Denied (Linux)
```bash
sudo usermod -a -G dialout $USER
# Log out and back in
```

### Upload Fails
```bash
# Reset first, wait, then upload
mpremote connect PORT reset
sleep 3
python3 Smart_incubator/sync_firmware.py
```

### Out of Memory
```bash
# Check free space
mpremote connect PORT exec "import os; print(os.statvfs('/'))"

# Remove old files
mpremote connect PORT exec "import os; os.remove('/old_file.py')"

# Use compiled .mpy files (smaller)
mpy-cross Firmware/large_file.py
mpremote connect PORT cp large_file.mpy :/
```

### SD Card Issues
```bash
# Verify SD card
mpremote connect PORT exec "import os; print('/sd' in os.listdir('/'))"

# Format SD card
python3 Smart_incubator/format_sd_card.py

# Check SD card on computer
# Format as DOS_FAT_32 with MBR
```

---

## 📚 Full Documentation

- **[DEPLOYMENT_GUIDE.md](DEPLOYMENT_GUIDE.md)** - Complete deployment documentation
- **[QUICK_START.md](QUICK_START.md)** - Visual workflows with examples
- **[README.md](README.md)** - Main platform documentation
- **[DEPLOYMENT_README.md](DEPLOYMENT_README.md)** - Legacy deployment notes

---

## 💡 Pro Tips

1. **Use `Cmd+Shift+B` religiously** - It's the fastest way to deploy
2. **Format SD card before big experiments** - Ensures clean data collection
3. **Check REPL regularly** - Catch issues early
4. **Use `--force` sparingly** - Only when things are broken
5. **Mount filesystem for rapid development** - No upload needed!
6. **Keep configs in version control** - Easy to track experiment parameters
7. **Use VS Code tasks** - One click for everything

---

**Happy deploying! 🚀**

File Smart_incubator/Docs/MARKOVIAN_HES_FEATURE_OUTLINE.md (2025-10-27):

# Markovian Hidden Environmental States (HES) Feature Outline

## Overview

This document outlines the design and implementation plan for a Markovian Hidden Environmental States (HES) experimental framework for the Smart Incubator platform. This feature enables researchers to create complex, stochastic environmental sequences that test whether single-celled organisms can learn predictable versus unpredictable environmental patterns.

## Conceptual Background

### Hidden Environmental States (HES)
Based on the simulation model in the manuscript, Hidden Environmental States represent discrete environmental conditions, each characterized by specific actuator settings (temperature, LED intensity, vibration patterns). Organisms experience these states sequentially, with transitions governed by either:
- **Deterministic progression** (canonical sequence): HES 0 → 1 → 2 → 3 → 4 → 0...
- **Markovian stochastic transitions**: Probabilistic jumps to non-sequential states

### Markovian Transition Logic
The `Markovian_p` parameter controls environmental predictability:
- **Markovian_p = 0**: Fully deterministic, follows canonical sequence
- **Markovian_p = 0.5**: 50% chance of following sequence, 50% chance of random jump
- **Markovian_p = 1.0**: Fully stochastic, always jumps to random state

**Transition Probability Formula:**
```
If at HES[i]:
  - P(next = HES[i+1]) = 1 - Markovian_p
  - P(next = any other HES[j≠i+1]) = Markovian_p / (num_HES - 1)
```

**Example with 5 states, Markovian_p = 0.3, currently at HES 0:**
- P(HES 1) = 0.7 (70% chance to follow sequence)
- P(HES 2) = 0.075 (7.5% chance)
- P(HES 3) = 0.075 (7.5% chance)
- P(HES 4) = 0.075 (7.5% chance)
- P(HES 0) = 0.075 (7.5% chance to stay)

---

## Architecture Overview
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

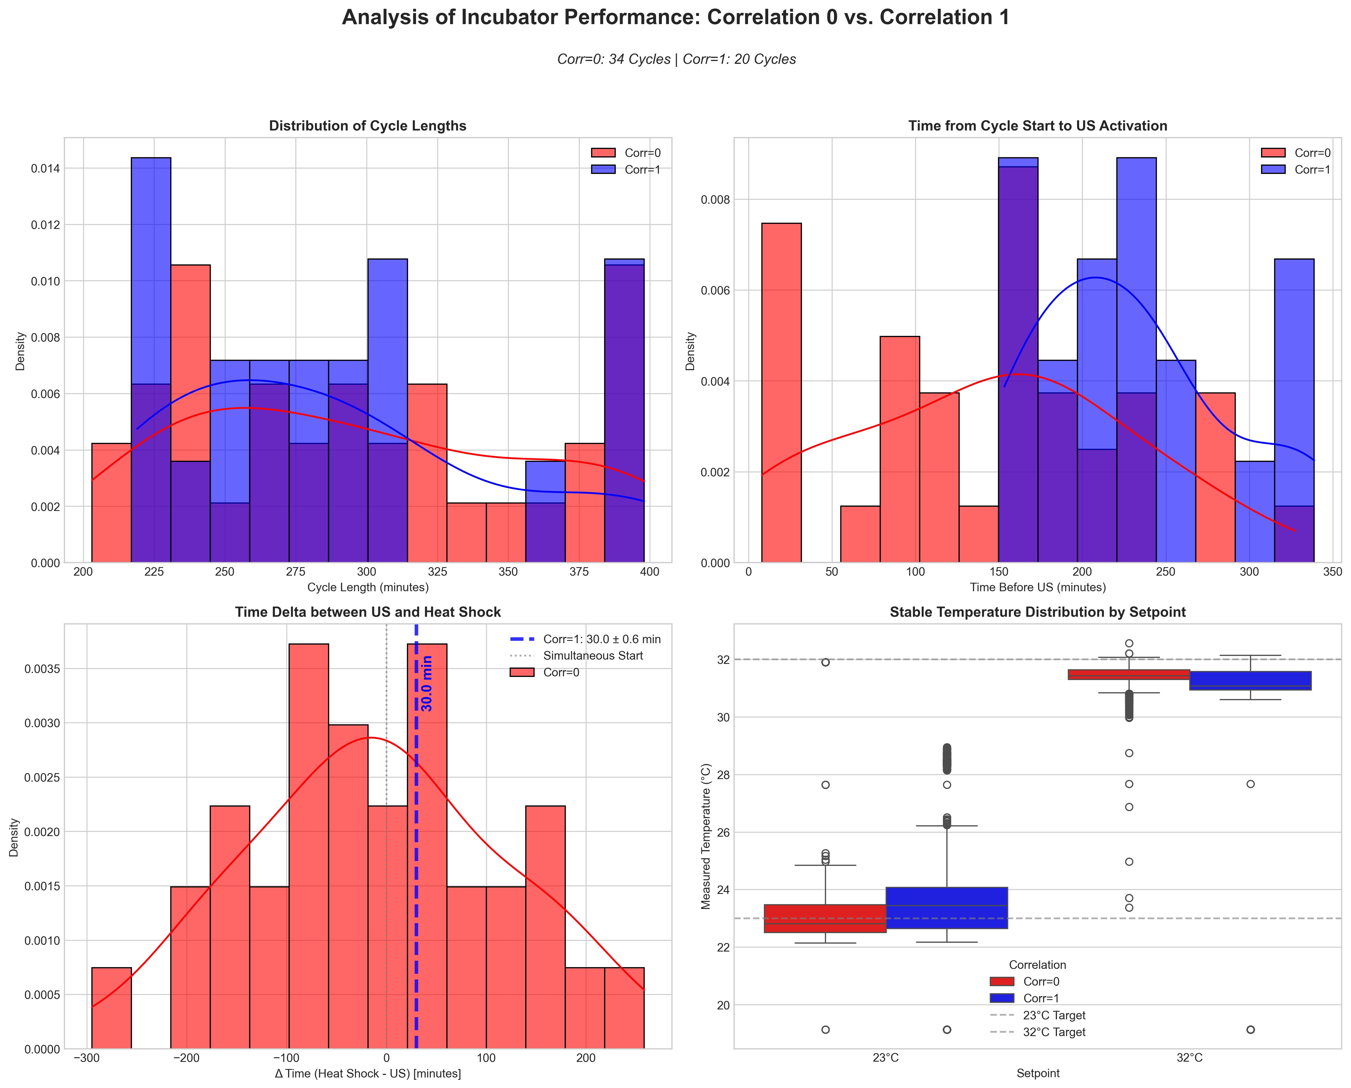
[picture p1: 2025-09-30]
Smart_incubator/Docs/custom_analysis_comparison_improved.png

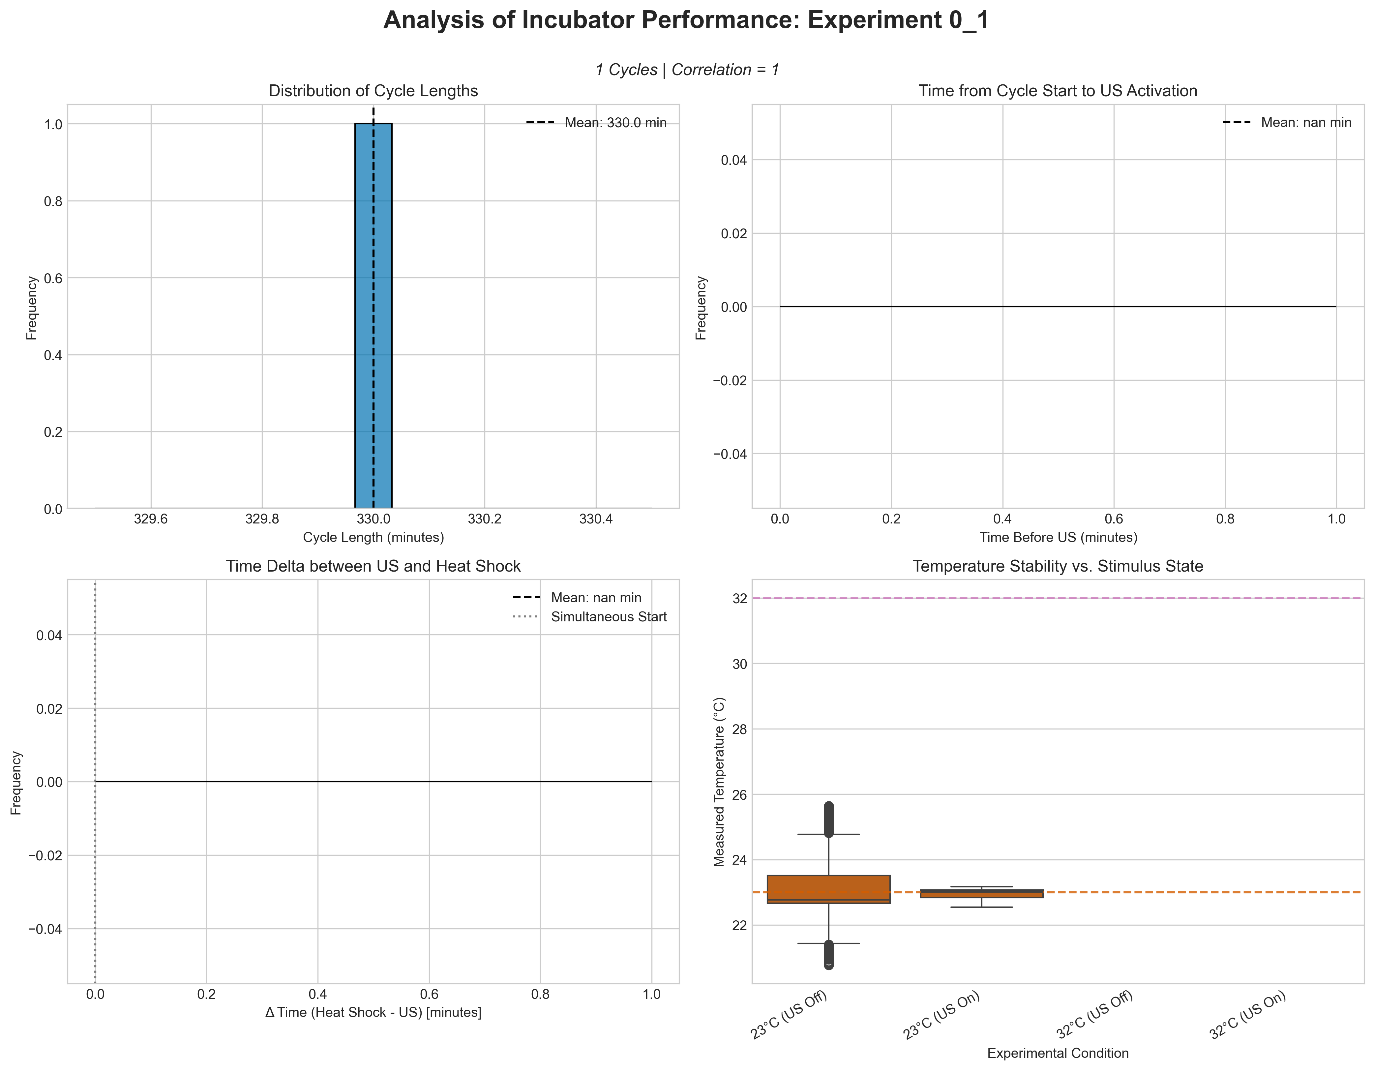
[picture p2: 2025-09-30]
Smart_incubator/Docs/analysis_0_1_publish_ready.png

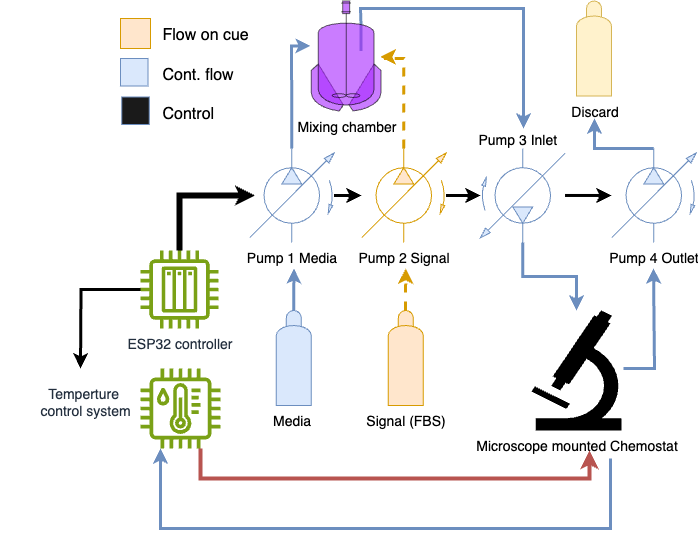
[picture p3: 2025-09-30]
Microscope_mounted_chemostat/Docs/MCMClayout.drawio (1).png

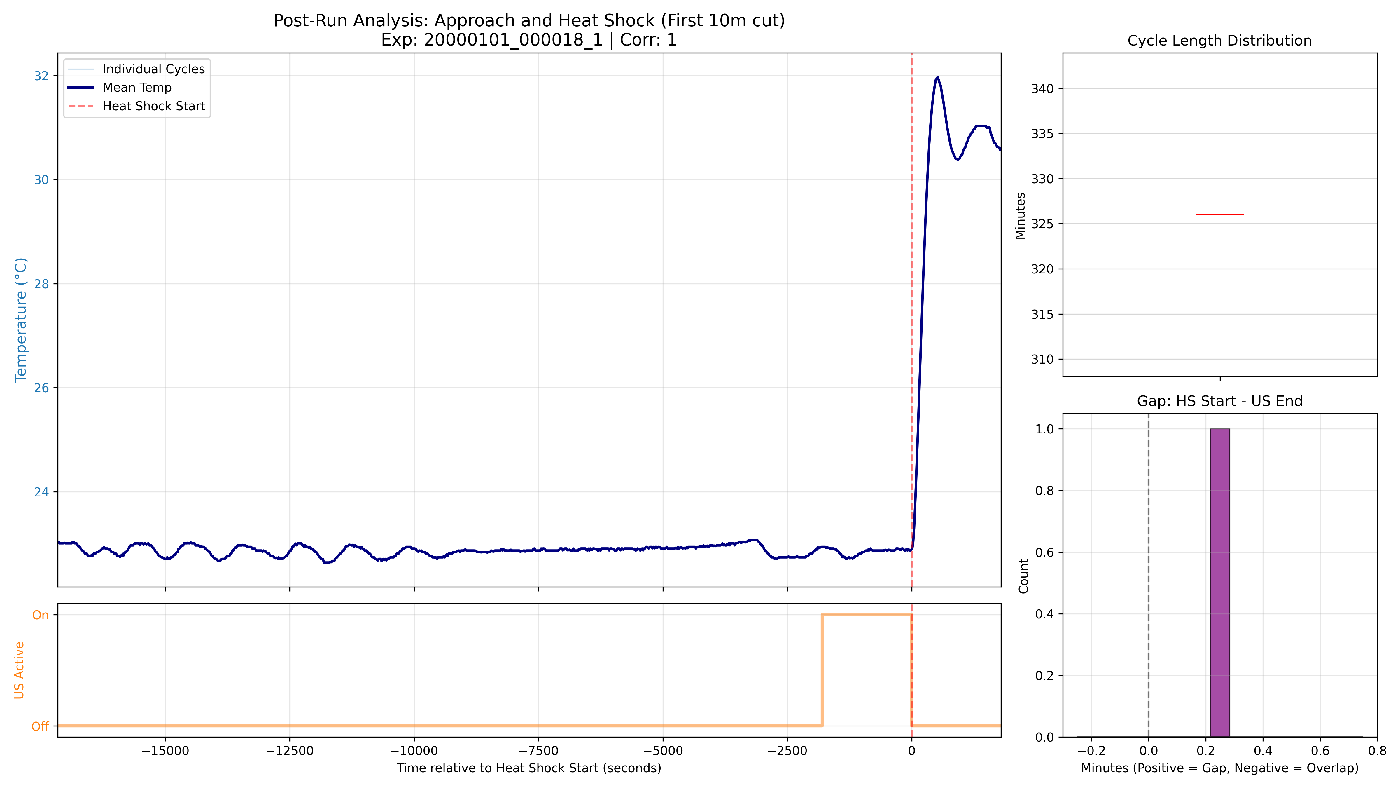
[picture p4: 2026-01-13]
post_run_analysis_20000101_000018_1_corr1.png

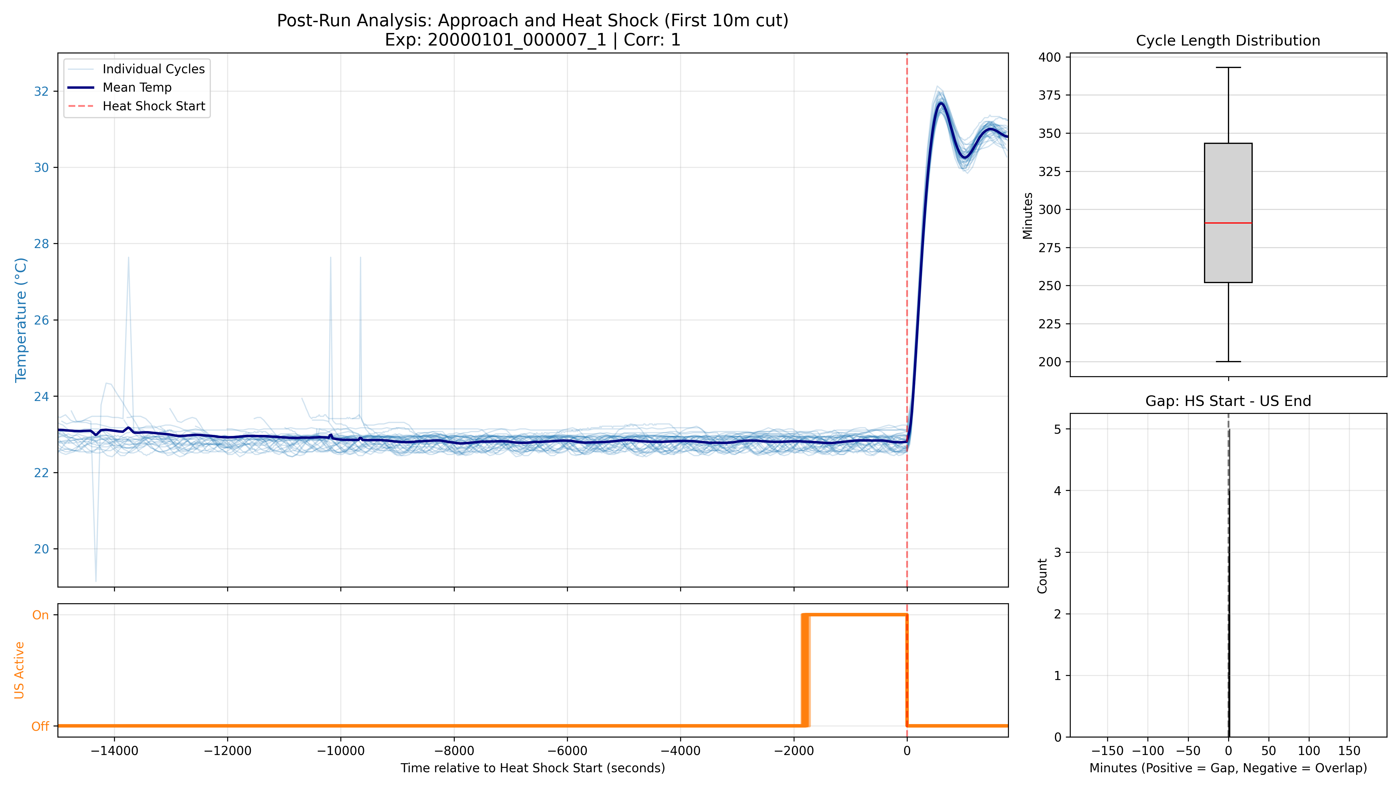
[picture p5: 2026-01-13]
post_run_analysis_20000101_000007_1_corr1.png

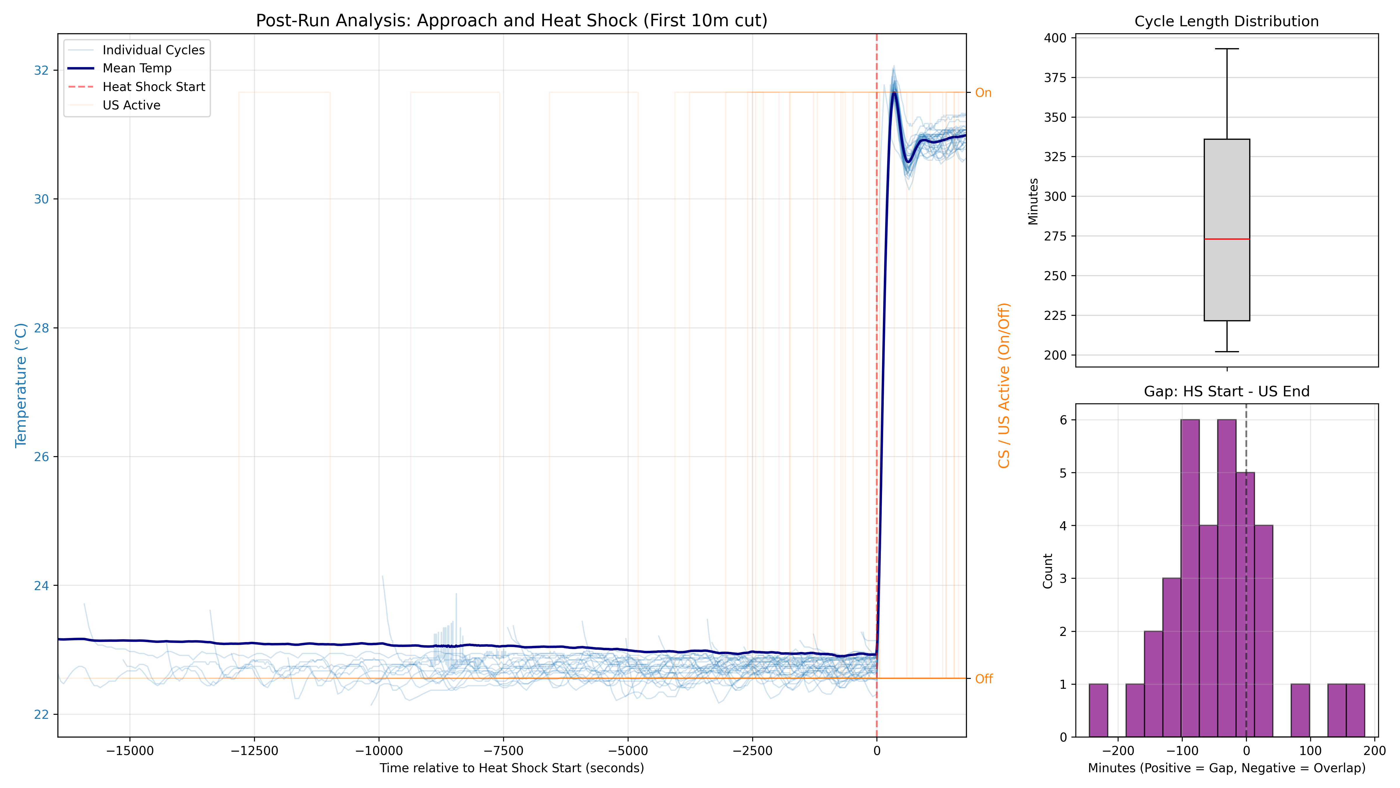
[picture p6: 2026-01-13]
post_run_analysis.png

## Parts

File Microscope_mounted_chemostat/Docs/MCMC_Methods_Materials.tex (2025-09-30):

\section{MCMC Microscope Chemostat Platform}

The MCMC (Microscope Chemostat) platform is an automated experimental system designed to convert standard laboratory microscopes into sophisticated continuous culture reactors with real-time cell counting and adaptive control capabilities. The system enables long-term microbiology experiments with precise environmental control, automated cell density management, and coordinated multi-channel flow control. Built on a distributed ESP32 microcontroller architecture with Python-based host coordination, the platform supports fully autonomous chemostat, turbidostat, and morbidostat operation modes with comprehensive data logging and real-time monitoring.

The platform's design philosophy centers on creating a modular, scalable system where multiple independent culture channels can be operated simultaneously under different experimental conditions. This approach allows researchers to conduct comparative studies, test multiple hypotheses in parallel, and perform high-throughput screening experiments while maintaining precise temporal and environmental control over each culture system.

\subsection{Hardware and System Architecture}

The MCMC platform employs a distributed microcontroller architecture consisting of multiple ESP32-WROOM-32 nodes (240 MHz dual-core) orchestrated through MQTT communication protocols. The system design emphasizes modularity, fault tolerance, and real-time responsiveness, with comprehensive safety features and automated error recovery mechanisms.

\begin{table}[H]
\centering
\caption{MCMC Platform Hardware Components and GPIO Assignments}
\begin{tabularx}{\textwidth}{|l|l|X|l|}
\hline
\textbf{Component} & \textbf{Interface} & \textbf{Pin(s) \& Function} & \textbf{Specifications} \\
\hline
\multicolumn{4}{|c|}{\textbf{ESP-T Temperature Controller}} \\
\hline
Control Unit & --- & ESP32-WROOM-32 & 240 MHz dual-core, 520 KB SRAM \\
\hline
Temperature Sensing & SPI & MAX31865 + PT100 RTD & SCK 18, MOSI 23, MISO 19, CS 5 \\
\hline
Thermal Actuators & PWM (1 kHz) & PTC Heater & Pin 33, MOSFET-controlled, 0-100\% duty \\
\hline
 & PWM (1 kHz) & TEC Peltier Cooler & Pin 27, MOSFET-controlled, 0-100\% duty \\
\hline
Data Storage & SPI & MicroSD Card Module & Daily rotating CSV logs, FAT32 \\
\hline
Status Indication & Digital & Status LED & Pin 2, heating/cooling/idle/emergency states \\
\hline
\multicolumn{4}{|c|}{\textbf{ESP-C Channel Controllers (3×)}} \\
\hline
Peristaltic Pumps & PWM (20 kHz) & Media Pump & Pin 25, 0-100\% flow control \\
\hline
 & PWM (20 kHz) & Signal Pump & Pin 26, independent injection control \\
\hline
 & PWM (20 kHz) & Chamber Pump & Pin 27, coordinated with media pump \\
\hline
 & PWM (20 kHz) & Overflow Pump & Pin 32, 3× duration multiplier \\
\hline
Illumination & PWM (20 kHz) & LED Array & Pin 33, 0-100\% intensity control \\
\hline
Status Indication & Digital & Built-in LED & Pin 2, operational status display \\
\hline
\multicolumn{4}{|c|}{\textbf{Host Computer Integration}} \\
\hline
Microscope Camera & USB & Standard USB Camera & 640×480 resolution, real-time imaging \\
\hline
MQTT Broker & Network & Mosquitto Broker & 192.168.1.x, no authentication \\
\hline
Analysis Engine & Software & Cellpose Integration & CPU/GPU cell segmentation \\
\hline
\end{tabularx}
\end{table}

\subsubsection{Distributed Control Architecture}

The system employs a hierarchical control architecture that separates low-level hardware control from high-level experimental logic, ensuring modularity, scalability, and operational resilience:

\textbf{Hardware Layer (ESP32 Nodes):}
\begin{enumerate}
\item \textbf{ESP-T Temperature Controller:} Dedicated PID temperature regulation with safety cutoffs and sensor fault detection
\item \textbf{ESP-C Channel Controllers:} Independent flow control nodes managing 4 pumps + LED per culture channel
\item \textbf{Distributed Communication:} MQTT-based inter-node coordination with automatic reconnection
\item \textbf{Local Data Logging:} Each node maintains 24-hour rolling logs on microSD cards for fault tolerance
\end{enumerate}

\textbf{Host Coordination Layer (Python):}
\begin{enumerate}
\item \textbf{MQTT Broker:} Central message routing using Mosquitto (no authentication for research environment)
\item \textbf{Mode Controllers:} Chemostat, turbidostat, morbidostat, and aggregation-stat algorithm implementations
\item \textbf{Real-time Analysis:} Cellpose-based cell counting with automatic GPU/CPU fallback
\item \textbf{Experiment Coordination:} Multi-channel synchronization and parameter management
\end{enumerate}

\textbf{Key Software Features:}
\begin{itemize}
\item \textbf{Asynchronous operation} with non-blocking timer-based control loops
\item \textbf{Automatic error recovery} with exponential backoff retry mechanisms  
\item \textbf{Real-time telemetry} at 1 Hz sampling rate for all system parameters
\item \textbf{Emergency stop capability} with immediate hardware shutdown via global MQTT command
\item \textbf{Hot-swappable configuration} allowing parameter updates during operation
\item \textbf{Comprehensive logging} with structured JSON data format and cryptographic integrity checking
\end{itemize}

\subsection{Flow Control and Pump Coordination System}

\subsubsection{Multi-Channel Peristaltic Pump System}

The MCMC platform employs a sophisticated four-pump coordination system per channel, optimized for continuous culture applications with precise flow rate control and temporal coordination.

\textbf{Pump Configuration and Flow Scheme:}
\begin{itemize}
\item \textbf{Media Pump (Pump 1):} Fresh medium delivery with calibrated flow rates (0-15 ml/h)
\item \textbf{Signal Pump (Pump 2):} Independent signal/drug injection with precise timing control
\item \textbf{Chamber Pump (Pump 3):} Culture delivery pump, coordinated with media pump for mixing
\item \textbf{Overflow Pump (Pump 4):} Waste removal with 3× duration multiplier for complete evacuation
\end{itemize}

\textbf{Flow Coordination Algorithm:}
\begin{itemize}
\item \textbf{Synchronized operation:} Media and chamber pumps operate simultaneously for T seconds
\item \textbf{Extended overflow:} Overflow pump continues for 3T seconds to ensure complete evacuation
\item \textbf{Independent signaling:} Signal pump operates on-demand with separate timing control
\item \textbf{Non-blocking operation:} Timer-based control allows command acceptance during active cycles
\end{itemize}

\textbf{PWM Control and Calibration:}
The system employs high-frequency PWM control (20 kHz) with comprehensive calibration for precise flow rate delivery:

\begin{itemize}
\item \textbf{Resolution:} 13-bit PWM resolution (8,191 discrete levels) for fine flow control
\item \textbf{Calibration model:} Linear relationship: Flow Rate (ml/h) = a × PWM\% + b
\item \textbf{Voltage profiles:} Configurable for 5V or 12V pump operation with optimized frequency settings
\item \textbf{Pulsing capability:} Sub-minimum flow rates achieved through duty cycling for ultra-low delivery rates
\item \textbf{Real-time adjustment:} Flow rates modifiable during operation without interrupting other pumps
\end{itemize}

\textbf{Flow Rate Performance:}
\begin{itemize}
\item \textbf{Range:} 0.1-15 ml/h per pump with ±5\% accuracy after calibration
\item \textbf{Minimum flow:} 0.05 ml/h achieved through 1-minute duty cycling
\item \textbf{Response time:} <1 second for flow rate changes
\item \textbf{Stability:} ±2\% variation during continuous operation over 24-hour periods
\end{itemize}

\subsubsection{Temperature Regulation System}

The thermal control system employs a dual-actuator PID controller optimized for biological temperature ranges with comprehensive safety features and fault tolerance.

\textbf{PID Controller Configuration:}
\begin{itemize}
\item \textbf{Asymmetric gains:} Heating gain = 1.0, Cooling gain = 1.35 (optimized for actuator characteristics)
\item \textbf{Update frequency:} 1 Hz control loop with 250 ms sensor sampling
\item \textbf{Safety cutoff:} Hard limit at 42°C with immediate actuator shutdown
\item \textbf{Anti-windup protection:} Prevents integral term saturation during large setpoint changes
\item \textbf{Deadband control:} ±0.2°C around setpoint to prevent actuator chatter
\end{itemize}

\textbf{Dual-Actuator Control:}
\begin{itemize}
\item \textbf{PTC Heater (Pin 33):} MOSFET-controlled PWM for heating from ambient to 40°C
\item \textbf{TEC Peltier Cooler (Pin 27):} MOSFET-controlled PWM with thermal cycling protection
\item \textbf{Coordinated operation:} Automatic switching between heating and cooling modes
\item \textbf{Thermal protection:} Maximum duty cycle limits to prevent actuator damage
\end{itemize}

\textbf{Temperature Sensing and Validation:}
\begin{itemize}
\item \textbf{Sensor:} PT100 platinum RTD with MAX31865 digital converter
\item \textbf{Accuracy:} ±0.1°C absolute accuracy over 15-40°C operating range
\item \textbf{Noise filtering:} Median filtering of 5 successive readings with outlier rejection
\item \textbf{Fault detection:} Automatic detection of sensor opens, shorts, and wiring faults
\item \textbf{Retry logic:} Up to 3 attempts per reading with exponential backoff
\end{itemize}

\section{Real-Time Cell Analysis and Control Modes}

The MCMC platform implements sophisticated closed-loop control algorithms based on real-time cell counting and analysis, enabling autonomous adaptation to culture dynamics.

\subsection{Cellpose Integration and Image Processing}

\textbf{Real-Time Cell Counting Pipeline:}
\begin{itemize}
\item \textbf{Image acquisition:} USB microscope camera with 640×480 resolution at configurable intervals
\item \textbf{Cellpose processing:} Deep learning-based cell segmentation with cyto model
\item \textbf{GPU/CPU fallback:} Automatic hardware detection with performance optimization
\item \textbf{Cell density calculation:} Automated conversion from cell counts to cells/ml with volume calibration
\item \textbf{Quality control:} Image quality assessment and automatic retry on poor segmentation
\end{itemize}

\textbf{Analysis Performance:}
\begin{itemize}
\item \textbf{Processing time:} 2-5 seconds per frame (GPU) or 10-30 seconds (CPU)
\item \textbf{Detection accuracy:} >95\% for well-separated individual cells
\item \textbf{Density range:} 10³-10⁷ cells/ml with automatic dilution factor adjustment
\item \textbf{Temporal resolution:} Configurable from 30 seconds to 10 minutes between analyses
\end{itemize}

\subsection{Autonomous Control Modes}

\textbf{Chemostat Mode:}
\begin{itemize}
\item \textbf{Principle:} Constant dilution rate with continuous medium supply
\item \textbf{Control parameter:} Fixed flow rate independent of cell density
\item \textbf{Applications:} Steady-state physiology studies, metabolic characterization
\item \textbf{Typical parameters:} Dilution rates 0.1-1.0 h⁻¹ with 24-72 hour equilibration
\end{itemize}

\textbf{Turbidostat Mode:}
\begin{itemize}
\item \textbf{Principle:} Constant cell density maintenance through feedback control
\item \textbf{Control parameter:} Cell density setpoint (default: 1×10⁶ cells/ml)
\item \textbf{Trigger threshold:} Configurable hysteresis band (default: ±20\% of setpoint)
\item \textbf{Response algorithm:} Proportional dilution based on density deviation
\item \textbf{Applications:} Growth rate measurements, evolutionary experiments
\end{itemize}

\textbf{Morbidostat Mode:}
\begin{itemize}
\item \textbf{Principle:} Adaptive drug concentration based on growth response
\item \textbf{Control logic:} Increase drug concentration when growth exceeds threshold
\item \textbf{Drug delivery:} Automated via signal pump with precise concentration control
\item \textbf{Applications:} Antibiotic resistance evolution, drug efficacy screening
\end{itemize}

\textbf{Signal Injection System:}
\begin{itemize}
\item \textbf{Trigger conditions:} Cell density thresholds, time-based schedules, or manual commands
\item \textbf{Injection precision:} ±1\% volume accuracy with 0.1 ml minimum delivery
\item \textbf{Coordination:} Synchronized with chemostat cycles to prevent washout
\item \textbf{Multi-modal delivery:} Support for multiple signal types per experiment
\end{itemize}

\section{Communication Protocol and Data Management}

The MCMC platform implements a comprehensive MQTT-based communication system with structured data logging and integrity verification mechanisms.

\subsection{MQTT Communication Architecture}

\textbf{Topic Structure and Message Protocol:}

\begin{table}[H]
\centering
\caption{MQTT Topic Structure and Payload Specifications}
\begin{tabularx}{\textwidth}{|l|l|X|}
\hline
\textbf{Topic Pattern} & \textbf{Direction} & \textbf{JSON Payload Example} \\
\hline
\multicolumn{3}{|c|}{\textbf{Command Topics (Host → ESP32)}} \\
\hline
\texttt{cmd/chan\{n\}/pump\{m\}} & Host → ESP-C & \texttt{\{"duty": 75, "dur": 60\}} \\
\hline
\texttt{cmd/chan\{n\}/led} & Host → ESP-C & \texttt{\{"duty": 50, "dur": 120\}} \\
\hline
\texttt{cmd/temp} & Host → ESP-T & \texttt{\{"setpoint": 37.0\}} \\
\hline
\texttt{cmd/kill} & Host → All & \texttt{\{\}} (Emergency stop) \\
\hline
\multicolumn{3}{|c|}{\textbf{Status Topics (ESP32 → Host)}} \\
\hline
\texttt{stat/temp} & ESP-T → Host & \texttt{\{"T": 36.8, "setpoint": 37.0, "PTC\_PWM": 25, "TEC\_PWM": 0, "mode": "heating"\}} \\
\hline
\texttt{stat/chan\{n\}} & ESP-C → Host & \texttt{\{"pump\_duty": [0, 0, 75, 25], "led\_duty": 0, "cycle\_active": true\}} \\
\hline
\multicolumn{3}{|c|}{\textbf{Sensor Topics (Host ↔ Host)}} \\
\hline
\texttt{sensor/cellpose\{n\}/count} & Analysis → Control & \texttt{\{"count": 1250000, "timestamp": 1700000000.123\}} \\
\hline
\texttt{config/chan\{n\}/turbido} & Control → ESP-C & \texttt{\{"enabled": true, "target": 1000000, "threshold": 1200000\}} \\
\hline
\end{tabularx}
\end{table}

\textbf{Communication Features:}
\begin{itemize}
\item \textbf{QoS Level 1:} At-least-once delivery for critical commands
\item \textbf{Retained messages:} System state persistence across reconnections
\item \textbf{Automatic reconnection:} Exponential backoff with maximum 60-second intervals
\item \textbf{Message validation:} JSON schema validation with error reporting
\item \textbf{Timestamp synchronization:} Unix timestamp precision for temporal correlation
\end{itemize}

\subsection{Data Logging and Integrity Management}

\textbf{Hierarchical Data Organization:}

\begin{verbatim}
experiment_data/
├── [EXPERIMENT_ID]/              // Format: YYYYMMDD_HHMMSS_mode
│   ├── metadata/
│   │   ├── experiment_config.json    // Initial parameters and settings
│   │   ├── calibration_data.json     // Pump and sensor calibrations
│   │   └── system_manifest.json      // File integrity checksums
│   ├── temperature/
│   │   ├── esp_t_local_YYYYMMDD.csv  // Local ESP-T logs (backup)
│   │   └── temperature_1hz.csv       // Host-aggregated temperature data
│   ├── channels/
│   │   ├── channel_1_status.csv      // Pump duties, LED states, cycle info
│   │   ├── channel_1_cellpose.csv    // Cell counts and analysis data
│   │   └── channel_1_events.json     // Discrete event logging
│   └── analysis/
│       ├── growth_curves.csv         // Derived growth rate data
│       ├── control_events.json       // Mode switching and interventions
│       └── summary_statistics.json   // Experiment-wide metrics
\end{verbatim}

\textbf{Data Integrity and Quality Assurance:}
\begin{itemize}
\item \textbf{Cryptographic validation:} SHA-256 checksums for all data files
\item \textbf{Temporal consistency:} Automatic timestamp validation and gap detection
\item \textbf{Cross-validation:} Parameter consistency checks between ESP32 nodes and host
\item \textbf{Redundant storage:} Local ESP32 logging provides backup for network failures
\item \textbf{Real-time monitoring:} Continuous data quality assessment with automated alerts
\end{itemize}

\textbf{Analysis and Export Capabilities:}
\begin{itemize}
\item \textbf{Real-time visualization:} Live plots of key parameters during experiments
\item \textbf{Standard format export:} CSV, JSON, and HDF5 format support
\item \textbf{Metadata preservation:} Complete experimental provenance for reproducibility
\item \textbf{Statistical analysis:} Built-in growth rate calculation and curve fitting
\item \textbf{Integration support:} Compatible with R, Python, and MATLAB analysis pipelines
\end{itemize}

\subsection{Safety Systems and Error Handling}

\textbf{Multi-Level Safety Architecture:}
\begin{itemize}
\item \textbf{Hardware level:} Temperature cutoffs, pump current limiting, watchdog timers
\item \textbf{Firmware level:} Parameter validation, sensor fault detection, emergency stops
\item \textbf{Communication level:} Command authentication, rate limiting, timeout handling
\item \textbf{System level:} Global emergency stop, automatic safe-state transitions
\end{itemize}

\textbf{Fault Tolerance and Recovery:}
\begin{itemize}
\item \textbf{Network resilience:} Automatic WiFi reconnection with local operation continuity
\item \textbf{Sensor redundancy:} Multiple validation methods for critical measurements
\item \textbf{Graceful degradation:} System continues with reduced functionality during partial failures
\item \textbf{State recovery:} Automatic restoration of operational parameters after power cycles
\item \textbf{Diagnostic logging:} Comprehensive error tracking for system maintenance
\end{itemize}

\end{document}

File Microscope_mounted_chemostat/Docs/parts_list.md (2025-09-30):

# Microscope Mounted Chemostat - Parts List

Complete bill of materials for building the MCMC platform.

## Electronics Components

### Microcontroller
| Item | Specification | Quantity | Notes |
|---|---|---|---|
| ESP32-WROOM-32 Development Board | 240 MHz dual-core, WiFi/Bluetooth | 1 | Main controller |
| USB Cable (Micro-B or Type-C) | Data + Power capable | 1 | For programming and power |

### Power Supply
| Item | Specification | Quantity | Notes |
|---|---|---|---|
| 12V DC Power Supply | 12V, 2-3A minimum | 1 | For peristaltic pumps |
| Power Jack Adapter | 5.5mm x 2.1mm | 1 | DC barrel jack |
| Step-down Converter (optional) | 12V to 5V, 2A | 1 | If not using USB power for ESP32 |

### MOSFETs and Drivers
| Item | Specification | Quantity | Notes |
|---|---|---|---|
| IRL44ZN N-Channel MOSFET | Logic-level, 60V, 47A | 5 | 4 for pumps, 1 for LED |
| 10kΩ Resistors | 1/4W | 5 | Pull-down for MOSFET gates |
| 1N4007 Diodes | 1A, 1000V | 5 | Flyback protection |

### PCB Components
| Item | Specification | Quantity | Notes |
|---|---|---|---|
| Screw Terminal Blocks | 2-position, 5mm pitch | 6 | For pump/LED connections |
| Header Pins | 2.54mm pitch, male | 40 pins | For ESP32 mounting |
| Female Headers | 2.54mm pitch | 40 pins | ESP32 socket (optional) |

## Pumps and Fluidics

### Peristaltic Pumps
| Item | Specification | Quantity | Notes |
|---|---|---|---|
| 12V Peristaltic Pump | Variable speed, 0-100 ml/min | 4 | DC motor driven |
| Pump Tubing | Silicone, 3mm ID | 2m | For each pump |
| Pump Head | Compatible with tubing | 4 | Usually included with pump |

**Recommended Pump Models:**
- Longer Precision Pump BT100-1L
- Kamoer KCP-PRO series
- Generic 12V peristaltic dosing pump

### Tubing and Connectors
| Item | Specification | Quantity | Notes |
|---|---|---|---|
| Silicone Tubing | 3mm ID, 5mm OD | 5m | Main fluid lines |
| Luer Lock Connectors | Male/Female | 10 | For connections |
| T-Connectors | 3mm barb | 4 | For mixing points |
| Check Valves | 3mm barb, one-way | 4 | Prevent backflow |
| Tubing Clamps | Adjustable | 8 | For setup and maintenance |

## Chamber and Microscopy

### Culture Chamber
| Item | Specification | Quantity | Notes |
|---|---|---|---|
| Glass Microscope Slide | 75mm x 25mm | 2 | Top and bottom |
| Silicone Spacer | Custom cut, 1-2mm thick | 1 | Chamber walls |
| Inlet/Outlet Ports | Luer lock compatible | 4 | Chamber connections |

**Note:** 3D-printed chamber available in `Hardware/3D_Models/`

### Illumination
| Item | Specification | Quantity | Notes |
|---|---|---|---|
| White LED Array | 12V, high power | 1 | PWM controlled |
| LED Heatsink | Aluminum, 40mm | 1 | For LED cooling |
| Thermal Paste | Standard | 1 tube | LED mounting |

### Microscope Integration
| Item | Specification | Quantity | Notes |
|---|---|---|---|
| USB Microscope Camera | 640×480 minimum | 1 | For Cellpose (optional) |
| Camera Mount | Custom or universal | 1 | Align with chamber |

## 3D Printed Components

All STL files available in `Hardware/3D_Models/`

| Item | File Name | Quantity | Material | Notes |
|---|---|---|---|---|
| Chemostat Chamber Box | Multi channel chemostat v14 box.stl | 1 | PLA/PETG | Main enclosure |
| Temperature Module Box | Multi channel chemostat v5 TEMP.stl | 1 | PLA/PETG | Optional |
| Plant Maze Base | plant maze.stl | 1 | PLA | For aggregation studies |
| Plant Maze Lid | plant maze lid.stl | 1 | PLA | Covers maze |

**Print Settings:**
- Layer height: 0.2mm
- Infill: 20%
- Supports: As needed
- Material: PLA or PETG recommended

## PCB Manufacturing

### Gerber Files
Located in `Hardware/PCB/`:
- All layers included (copper, mask, silkscreen, edges)
- Drill files (PTH and NPTH)
- Job file for manufacturer specifications

**Recommended PCB Specs:**
- Layers: 2
- Thickness: 1.6mm
- Copper weight: 1 oz (35 μm)
- Surface finish: HASL or ENIG
- Minimum trace width: 0.3mm
- Minimum clearance: 0.3mm

**Manufacturers:**
- JLCPCB
- PCBWay
- OSH Park
- Seeed Studio Fusion

## Sensors and Measurement (Optional)

### Temperature Sensing
| Item | Specification | Quantity | Notes |
|---|---|---|---|
| PT100 RTD Sensor | 3-wire, Class A | 1 | Precise temperature |
| MAX31865 Module | RTD-to-digital converter | 1 | SPI interface |

### pH Measurement (Future)
| Item | Specification | Quantity | Notes |
|---|---|---|---|
| pH Probe | Waterproof, 0-14 range | 1 | Optional addition |
| pH Interface Board | Analog or digital | 1 | Signal conditioning |

## Tools Required

### For Assembly
- Soldering iron and solder
- Wire strippers/cutters
- Screwdriver set (Phillips, flathead)
- Multimeter
- Heat shrink tubing
- Hot glue gun (for strain relief)

### For Calibration
- Analytical balance (0.01g precision)
- Graduated cylinder or pipette (10ml)
- Stopwatch or timer
- Distilled water

## Media and Reagents

### For *Capsaspora owczarzaki*
| Item | Purpose | Notes |
|---|---|---|
| ATCC 1034 Medium | Growth medium | Or equivalent |
| Fetal Bovine Serum | 5% in medium | Heat-inactivated |
| Antibiotics | Contamination prevention | Pen/Strep optional |
| Signal Compounds | Experimental stimuli | User-defined |

## Computer Requirements

### Host Computer (for Cellpose integration)
- **OS:** macOS, Linux, or Windows
- **RAM:** 8GB minimum, 16GB recommended
- **Processor:** Multi-core, 2.4GHz+
- **GPU:** Optional but recommended for Cellpose
- **Storage:** 100GB+ for image data

### Software
- **Python 3.8+** (for host control)
- **Mosquitto MQTT broker** (for remote control)
- **Cellpose** (for cell counting)
- **Thonny IDE** (for ESP32 programming)
- **OpenCV** (for image processing)

## Cost Estimate

### Budget Breakdown (USD, approximate)
| Category | Cost Range |
|---|---|
| Electronics (ESP32, MOSFETs, PCB) | $50-80 |
| Peristaltic Pumps (4×) | $60-200 |
| Tubing and Connectors | $30-50 |
| 3D Printing Materials | $20-40 |
| Power Supplies | $20-30 |
| Microscope Camera (optional) | $50-200 |
| Chamber Components | $20-40 |
| **Total (Basic)** | **$250-640** |
| **Total (with Camera)** | **$300-840** |

**Note:** Costs vary by supplier, quantity, and location. Bulk purchases reduce per-unit cost.

## Suppliers

### Electronics
- **Mouser Electronics** - mouser.com
- **DigiKey** - digikey.com
- **SparkFun** - sparkfun.com
- **Adafruit** - adafruit.com
- **AliExpress** - aliexpress.com (budget option)

### Pumps and Fluidics
- **Cole-Parmer** - coleparmer.com
- **Kamoer** - kamoer.com
- **Adafruit** - adafruit.com
- **AliExpress** - aliexpress.com

### 3D Printing Services
- **Shapeways** - shapeways.com
- **Sculpteo** - sculpteo.com
- **3D Hubs** - 3dhubs.com
- Local maker spaces

### PCB Manufacturing
- **JLCPCB** - jlcpcb.com
- **PCBWay** - pcbway.com
- **OSH Park** - oshpark.com

## Assembly Time

- **PCB Assembly:** 2-3 hours
- **Pump Integration:** 1-2 hours
- **3D Printing:** 10-20 hours (automated)
- **Chamber Assembly:** 1 hour
- **Software Setup:** 2-3 hours
- **Calibration:** 2-4 hours
- **Total:** ~15-30 hours (mostly automated printing)

## Storage and Organization

### Recommended Storage
- Small parts organizer for resistors, diodes
- Labeled containers for tubing sections
- Desiccant packs for electronics
- Clean, dry environment
- Temperature-controlled for media

## Calibration Materials

| Item | Purpose | Quantity |
|---|---|---|
| Distilled Water | Flow rate calibration | 500ml |
| Collection Vessels | Weighing pump output | 4× 50ml |
| Reference Weights | Balance calibration | Standard set |

## Maintenance Supplies

| Item | Purpose | Replacement Frequency |
|---|---|---|
| Pump Tubing | Prevent wear | Every 3-6 months |
| Silicone Grease | Seal maintenance | As needed |
| Isopropanol | Cleaning | As needed |
| Bleach Solution | Sterilization | As needed |
| Spare MOSFETs | Component failure | Keep 2-3 on hand |

## Quality Control Checklist

Before first use, verify:
- [ ] All solder joints secure and clean
- [ ] No shorts between power rails
- [ ] ESP32 boots and connects to WiFi
- [ ] All 4 pumps respond to PWM commands
- [ ] LED brightness adjustable
- [ ] Status LED indicates system state
- [ ] No leaks in fluidic connections
- [ ] Chamber maintains constant volume
- [ ] Temperature sensor (if used) reads accurately
- [ ] Data logging creates valid files
- [ ] Emergency stop functions correctly

## Safety Equipment

### Personal Protective Equipment
- Safety glasses
- Lab coat
- Nitrile gloves
- Closed-toe shoes

### Lab Safety
- Fire extinguisher nearby
- First aid kit
- Spill cleanup materials
- Biohazard disposal (if needed)
- Emergency contact numbers posted

## Documentation

Keep records of:
- Component serial numbers
- Calibration dates and values
- Maintenance log
- Experiment parameters
- Any modifications to design

## Support

For questions or issues:
- Check `MCMC_Software_Spec.md` for technical details
- Review `README.md` for troubleshooting
- Contact: [Your contact information]

---

**Last Updated:** September 2025  
**Version:** 1.0  
**Platform:** Microscope Mounted Chemostat (MCMC)

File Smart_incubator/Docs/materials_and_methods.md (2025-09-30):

 # Materials and Methods

## Simulation Environment

The simulation models a population of agents evolving in a cyclical environment with five discrete Hidden Environmental States (HES 0–4). Each day consists of a deterministic progression through all five states in sequence: $HES 0 \rightarrow HES 1 \rightarrow HES 2 \rightarrow HES 3 \rightarrow HES 4$, then cycling back to HES 0 on the following day. Each environmental state is characterized by three parameters: normalized temperature (T), carbon concentration (C), and nitrogen concentration (N), as shown in Table 1.

**Table 1: Environmental State Parameters**
| HES | Stage | Temperature (T) | Carbon (C) | Nitrogen (N) | C/N Ratio |
|-----|---|---|---|---|---|
| 0 | Dawn  | -0.34 | 0.1 | 1.0 | 0.1 |
| 1 | Morning | 1.38 | 1.0 | 0.1 | 10.0 |
| 2 | Midday  | -0.34 | 0.8 | 0.2 | 4.0 |
| 3 | Afternoon | 0.80 | 0.8 | 0.2 | 4.0 |
| 4 | Dusk | -1.49 | 0.1 | 1.0 | 0.1 |

At each environmental state transition, agents receive noisy observations of the true environmental parameters, with Gaussian noise ($\sigma = 0.2$) added to each dimension. To test robustness, we implemented an environmental stochasticity parameter ($\epsilon$) that introduces a probability of random state transitions instead of the deterministic sequence.

## Agent Architecture

Both agent types share an identical 452-bit boolean genome structure that encodes three key components:

### Genome Structure
1. **Phenotype Sequence (320 bits)**: Five 64-bit vectors, each encoding one of three possible phenotypes (P1, P2, or P3) using a nearest-centroid decoding scheme
2. **Baseline Transition Probability (100 bits)**: Encodes a probability $p_{\text{base}} \in [0,1]$ calculated as the proportion of '1' bits
3. **Temperature Sensitivity (32 bits)**: Encodes a sensitivity factor $C \in [-1,1]$ normalized around the midpoint

### Phenotype Transition Mechanics
Agent phenotype transitions are governed by a temperature-sensitive probabilistic mechanism. The effective transition probability at each environmental state is calculated as:

$P_{\text{effective}} = p_{\text{base}} \times (1 + C \times \text{norm}(\Delta T_{\text{obs}}))$

where $\Delta T_{\text{obs}}$ is the observed temperature change between consecutive states, and `norm()` normalizes the temperature change to [0,1]. This mechanism allows agents to use temperature cues to time their phenotype transitions appropriately within the daily cycle.

## Fitness Landscape

The fitness landscape implements a complex multi-peak structure with conditional bonuses designed to create valley-crossing challenges. The base fitness matrix assigns different fitness values to each phenotype in each environmental state:

**Base Fitness Matrix**
| HES | P1  | P2  | P3  |
|-----|-----|-----|-----|
| 0 | 1.0 | 0.1 | 0.6 |
| 1 | 0.3 | 0.8 | 0.6 |
| 2 | 0.3 | 0.8 | 0.6 |
| 3 | 0.3 | 0.8 | 1.2 |
| 4 | 1.0 | 0.1 | 0.6 |

### Conditional Fitness Mechanism
A critical feature of the fitness landscape is the preparatory phenotype mechanism. When an agent expresses phenotype P3 in HES 3, it activates a 2-step "preparation countdown" that enables maximum fitness (1.0) for phenotype P1 in subsequent nitrogen-rich states (HES 4 and HES 0). Without this preparation, P1 expression in nitrogen-rich states yields only 30% of its potential fitness (0.3), creating a temporal dependency that requires predictive adaptation.

## Mathematical Model of Fitness Dynamics

### Formal Model for Fitness Gain

We can formalize the fitness dynamics for both agent types as follows:

#### Blind Agent (BA) Fitness Model
For a BA agent i at time t, the fitness is determined solely by its genetically-encoded phenotype sequence:

$V_{\text{BA},i}(t) = \frac{1}{5} \sum_{h=0}^{4} F(G_i(t)[\phi_i(h)], h) - P_{\text{conditional}}(G_i(t), h)$

where:
- $G_i(t)$ is the genetically-determined phenotype sequence at generation t
- $\phi_i(h)$ is the phenotype index used in environmental state h
- $F(p,h)$ is the base fitness lookup function for phenotype p in state h
- $P_{\text{conditional}}$ accounts for the preparatory phenotype penalty (0.7 reduction if P1 used without P3 preparation)

The evolutionary dynamics follow:
$G_i(t+1) = G_i(t) \oplus M(\mu)$

where $M(\mu)$ represents bit-flip mutations with probability $\mu = 10^{-4}$.

#### Memory Bayesian Agent (MBA) Fitness Model
For an MBA agent i at time t, fitness incorporates both learned strategy and plasticity cost:

$V_{\text{MBA},i}(t) = \frac{1}{5} \sum_{h=0}^{4} [F(L_i(t)[\phi_i(h)], h) - C_{\text{plasticity}}(L_i(t), G_i(t))] - P_{\text{conditional}}(L_i(t), h)$

where:
- $L_i(t)$ is the learned phenotype sequence (posterior)
- $G_i(t)$ is the genomic phenotype sequence (prior)
- $C_{\text{plasticity}}$ is the continuous metabolic cost of plasticity

The plasticity cost function is defined as:
$C_{\text{plasticity}}(L_i, G_i) = \lambda_H \sum_{j=1}^{5} I(L_i[j] \neq G_i[j]) + \lambda_{KL} D_{KL}(p_{\text{learned}} \| p_{\text{genomic}})$

where $I()$ is the indicator function, $\lambda_H = 0.01$, and $\lambda_{KL} = 0.02$.

#### Learning Dynamics
The MBA's learned strategy evolves within lifetime according to:

$L_i(t, h+1) = \begin{cases} L_i(t, h) \oplus \text{Random\_phenotype\_switch} & \text{if } R(t,h) > 0.2 \text{ and } U(0,1) < \eta \\ L_i(t, h) & \text{otherwise} \end{cases}$

where $R(t,h) = F_{\text{optimal}}(h) - F_{\text{realized}}(t,h)$ is the regret function and $\eta = 0.3$ is the learning rate.

#### Genetic Assimilation Dynamics
When an MBA achieves sustained success, learned adaptations can be genetically assimilated:

If $\sum_{\tau=t-K+1}^{t} I(V_{\text{MBA},i}(\tau) > \theta) \ge K$, then $G_i(t+1)[j] \leftarrow L_i(t)[j]$

where K = 3 consecutive successful generations and $\theta = 0.65$ is the fitness threshold.

#### Comparative Advantage Model
The relative advantage of MBA over BA can be expressed as:

$\Delta(t) = E[V_{\text{MBA}}(t)] - E[V_{\text{BA}}(t)]$

This advantage is positive when the learning benefit outweighs the plasticity cost:
$E[F(L(t)) - F(G(t))] > E[C_{\text{plasticity}}(L(t), G(t))]$

The model predicts MBA advantage in predictable environments where learning can identify optimal strategies faster than mutation alone, but BA advantage in highly stochastic environments where plasticity costs exceed learning benefits.

## Agent Types

### Blind Agent (BA)
The Blind Agent represents a purely genetic strategy with no learning capability. Its behavior is entirely determined by its decoded genome:
- Phenotype sequence: Fixed at birth from genetic encoding
- Transition timing: Based solely on genetically encoded temperature sensitivity and baseline probability
- No plasticity cost or learning mechanism
- Relies entirely on mutation ($\mu = 10^{-4}$ per bit) and selection for adaptation

### Memory Bayesian Agent (MBA)
The MBA implements a dual-layer architecture enabling within-lifetime learning:

#### Dual-Layer Strategy
- **Genomic Layer (Prior)**: The inherited 452-bit genome representing the evolutionary baseline
- **Learning Layer (Posterior)**: A mutable copy of the phenotype sequence and transition probability that drives actual behavior

#### Plasticity Cost
The MBA pays a continuous metabolic cost for any divergence between its learned strategy and genomic prior:

$C_{\text{plasticity}} = \lambda_H \times \sum(P_{\text{learned},i} \neq P_{\text{geno},i}) + \lambda_{KL} \times D_{KL}(p_{\text{learned}} \| p_{\text{geno}})$

where $\lambda_H = 0.01$ (Hamming distance cost) and $\lambda_{KL} = 0.02$ (KL divergence cost for transition probabilities).

#### Learning Mechanism
The MBA employs a regret-based "trial and error" learning system:

1. **Regret Calculation**: After each environmental state, agents calculate regret as the difference between optimal possible fitness and realized fitness
2. **Learning Trigger**: If regret > 0.2, learning is activated with probability $\eta = 0.3$
3. **Phenotype Update**: Random selection of alternative phenotypes for the current sequence position
4. **Probability Update**: Gradual adjustment of transition probability toward an optimal target ($p_{\text{target}} = 0.9$)

#### Genetic Assimilation
Successful learned strategies can be permanently encoded into the genome through genetic assimilation. When an agent achieves high fitness (>0.65) for 3 consecutive days in a given sequence position, the learned phenotype for that position is written back to the genome, reducing future plasticity costs and making the adaptation heritable.

## Population Dynamics

Evolution proceeds via a Moran process maintaining constant population size:

1. **Parent Selection**: Agents are selected for reproduction with probability proportional to their daily fitness
2. **Victim Selection**: A random agent is chosen for replacement
3. **Offspring Production**: The parent produces a clonal offspring subject to mutation
4. **Mutation**: Each genome bit flips with probability $\mu = 10^{-4}$ (identical for both BA and MBA agent types)

## Experimental Protocols

### Core Evolution Experiments
Independent populations of 100 BA-only, 100 MBA-only, and mixed populations (50 BA + 50 MBA) were evolved for 500 days across 30 independent replicates. Daily fitness, population entropy, and plasticity costs were recorded.

### Stochasticity Stress Test
Mixed populations (50 BA + 50 MBA) were evolved under varying environmental noise levels ($\epsilon$ = 0.0 to 1.0 in increments of 0.05) for 200 days across 10 replicates per noise level to identify the predictability threshold where plasticity becomes maladaptive.

### Genetic Lock-in Test
Populations were evolved in the standard environment for 300 days, then subjected to a permanent environmental shift (reversed HES sequence order) to test adaptive flexibility. Recovery dynamics were monitored for an additional 200 days.

### Long-term Competition
Mixed populations (500 BA + 500 MBA) were co-evolved for 100,000 days to assess long-term evolutionary stability and the emergence of evolutionary rescue effects.

## Data Collection and Analysis

### Fitness Tracking
Daily fitness was calculated as the mean fitness across all five environmental states within each day. Final daily fitness for MBAs included subtraction of plasticity costs.

### Population Entropy
Shannon entropy was calculated from the distribution of phenotype sequences within each population: $H = -\sum(p_i \times \log_2(p_i))$, where $p_i$ is the frequency of sequence i.

### Muller Plots
Population genetic dynamics were visualized using Muller plots showing the frequency trajectories of the 9 most common genotype sequences over time, with remaining sequences aggregated as "Other."

### Statistical Analysis
All experiments used multiple independent replicates with results reported as mean ± standard error of the mean (SEM). Population-level dynamics were averaged across replicates, and evolutionary trajectories were analyzed using time-series methods.

## Implementation Details

The simulation was implemented in Python using NumPy for numerical computations and SciPy for statistical functions. The complete codebase is structured as a modular package with separate components for:
- Agent classes (`mba_vs_ba_sim.agents`)
- Environmental dynamics (`mba_vs_ba_sim.env`)
- Population evolution (`mba_vs_ba_sim.population`)
- Experimental scripts (`scripts/`)

All random number generation used NumPy's PCG64 generator with explicit seed management for reproducibility. Computational experiments were designed to be fully deterministic given input parameters and random seeds.

## Smart Incubator Platform

The Smart Incubator is an automated experimental platform designed to subject cell cultures to complex, long-term environmental protocols. It provides precise control over temperature and allows for the timed delivery of physical stimuli (light and vibration). The system is built on a modular MicroPython framework, enabling robust, unattended operation for studying phenotypic plasticity, learning, and memory in microorganisms like *Capsaspora owczarzaki*.

### Hardware and System Architecture

The platform is built around an ESP32 microcontroller, which orchestrates all subsystems. The hardware components and their corresponding GPIO pin assignments are detailed in Table 2.

**Table 2: Smart Incubator Hardware Components and Pinout**
| Component | Interface | Pin(s) & Function |
|---|---|---|
| **Control Unit** | - | ESP32-WROOM-32 (240MHz) |
| **Temperature Sensing** | SPI | MAX31865 with PT100 RTD |
| | | SCK: 14, MOSI: 13, MISO: 12, CS: 5 |
| **Thermal Actuators** | PWM | PTC Heater (Heating, Pin 33) |
| | | TEC1 Peltier (Cooling, Pin 27) |
| **Conditional Stimuli** | PWM | LED Module (Light, Pin 25) |
| | | Vibration Motor (Vibration, Pin 16) |
| **Data Storage** | SPI | MicroSD Card Module |
| | | SCK: 14, MOSI: 13, MISO: 12, CS: 15 |
| **User Interface** | I2C | SSD1306 128x64 OLED Display |
| | | SCL: 22, SDA: 21 |

The software architecture is multi-layered, separating high-level experimental logic from hardware drivers to ensure modularity and resilience. This includes automated initialization with retry logic, comprehensive error handling, and memory management via periodic garbage collection.

### Thermal and Stimulus Control System

#### Thermal Regulation
Precise temperature control is achieved through a Proportional-Integral-Derivative (PID) controller that manages the PTC heater and TEC1 cooler. The PID parameters are tuned for the system's thermal properties (kp=6.0, ki=0.02, kd=1.5) and feature an anti-windup mechanism to prevent integral term overshoot. The controller operates within a deadband of -0.1°C to +0.5°C to minimize actuator oscillation.

To ensure measurement accuracy, the system employs an advanced noise-filtering protocol for the MAX31865 sensor. Each temperature reading is the median of 5 rapid samples, and a change-rate limiter discards spurious readings that deviate more than 5°C from the previous measurement. This results in highly stable thermal control, maintaining a basal temperature of 23°C with an accuracy of +0.45°C to +0.65°C and a heat shock temperature of 32°C with an accuracy of -0.52°C to -2.52°C, depending on the experimental protocol.

#### Stimulus Delivery
The system can deliver two types of unconditional stimuli (US): optical (LED) and mechanical (vibration). The intensity of each stimulus is independently configurable via PWM (0–100%). The vibration motor operates on a default pulsed interval of 20 seconds on and 60 seconds off to prevent motor overheating and reduce mechanical stress on the culture.

### Experimental Protocols

The incubator executes experiments in automated, unattended cycles. Each cycle's duration is randomized within a configurable range (default: 200–400 minutes) to prevent organismal entrainment to a fixed cycle length. A typical cycle consists of a prolonged basal temperature phase (default: 23°C) followed by a shorter heat shock phase (default: 32°C).

A key experimental parameter is the `correlation` mode, which defines the temporal relationship between the unconditional stimulus (US) and the heat shock (HS):
- **Non-Temporal (Mode 0):** The timing of both US and HS are randomized independently within the cycle. This creates a control condition with no predictive relationship between the cue and the stressor, resulting in a highly variable stimulus-stress delta (-58.1 ± 113.9 min).
- **Temporal (Mode 1):** The US is programmed to precede the HS by a precise, fixed interval (default: 30 minutes). This mode is used to test for predictive learning and enables highly precise cue-stress pairing, achieving a stimulus-stress delta of 30.0 ± 0.3 min.

### Data Acquisition and Integrity

The system logs a complete data snapshot every 10 seconds to a FAT32-formatted SD card. For each experimental run, a unique directory is created with the format `data/DDMMYYYY_correlation/`. The logged data includes:
- **`meta.json`**: A file containing all initial parameters for the experiment.
- **`cycle_[N]_TIMESTAMP.json`**: Individual JSON files for each 10-second snapshot, containing timestamp, current temperature, setpoint, PID output, power levels, and stimulus status.
- **`cycle_[N]_summary.json`**: A summary file generated at the end of each cycle with statistics such as min/max/average temperatures, duration, and error counts.
- **`manifest.json`**: A file that ensures data integrity by storing SHA-256 checksums for all data files written during the experiment. The system verifies these checksums to detect any file corruption.

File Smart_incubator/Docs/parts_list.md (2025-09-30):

# Smart Incubator - Bill of Materials (BOM)

**Complete parts list for building the Smart Incubator Platform**

This document provides a detailed bill of materials for constructing the Smart Incubator experimental platform. All components are readily available from standard electronics suppliers.

---

## Overview

The Smart Incubator consists of five main subsystems:
1. **Control & Processing**: ESP32 microcontroller and power management
2. **Temperature Regulation**: Sensors, heater, cooler, and drivers
3. **Stimulus Delivery**: LED and vibration modules with control
4. **Data Storage & Display**: SD card and OLED interface
5. **Mechanical & Assembly**: Housing, mounting, and connections

**Estimated Total Cost:** $180 - $320 USD (depending on component choices and vendors)

---

## 1. Control & Processing

### Microcontroller System

| Component | Specification | Quantity | Approx. Cost | Notes |
|---|---|---|---|---|
| ESP32-WROOM-32 Development Board | 240 MHz dual-core, 520 KB SRAM, WiFi/Bluetooth | 1 | $8-12 | NodeMCU-32S or DOIT ESP32 DevKit recommended |
| USB-to-Serial Adapter | CP2102 or CH340 (usually included with dev board) | 1 | Included | For programming and monitoring |
| Micro-USB Cable | Data cable, 1-2m length | 1 | $3-5 | Quality cable important for stable connection |

**Subtotal: $11-17**

### Power Supply

| Component | Specification | Quantity | Approx. Cost | Notes |
|---|---|---|---|---|
| 5V Power Supply | 5V 3-5A, USB or barrel connector | 1 | $8-15 | Must provide stable 3-5A for heater/cooler |
| 12V Power Supply | 12V 2-3A (if using 12V actuators) | 1 | $10-18 | Optional, for higher power heater/cooler |
| Voltage Regulator | LM7805 or LM2596 step-down | 1-2 | $2-5 | If voltage conversion needed |
| Power Distribution Board | Breadboard or custom PCB | 1 | $3-10 | For organizing power connections |

**Subtotal: $23-48 (depending on configuration)**

---

## 2. Temperature Regulation System

### Temperature Sensing

| Component | Specification | Quantity | Approx. Cost | Notes |
|---|---|---|---|---|
| MAX31865 RTD-to-Digital Converter | SPI interface, breakout board | 1 | $12-18 | Adafruit or generic breakout |
| PT100 RTD Temperature Sensor | Platinum resistance thermometer, 2-wire or 3-wire | 1 | $8-15 | Class A accuracy recommended |
| Reference Resistor | 430Ω ±0.1%, metal film | 1 | $0.50-2 | Critical for accuracy (usually included with MAX31865 breakout) |
| RTD Extension Wire | Silicone insulated, 0.5-1m | 1m | $3-5 | For sensor placement flexibility |

**Subtotal: $24-40**

### Heating System

| Component | Specification | Quantity | Approx. Cost | Notes |
|---|---|---|---|---|
| PTC Heating Element | 5V or 12V, 5-15W | 1 | $5-12 | Self-regulating, safe for biological use |
| Heater MOSFET | IRFZ44N or IRLZ44N, N-channel | 1 | $1-3 | Logic-level gate (Vgs < 5V) |
| MOSFET Gate Resistor | 10kΩ, 1/4W | 1 | $0.10 | Pull-down for safety |
| Flyback Diode | 1N4007 or similar, >1A | 1 | $0.20 | Protection for inductive loads |
| Heat Sink | TO-220 compatible, small | 1 | $1-3 | Optional but recommended |

**Subtotal: $7-21**

### Cooling System

| Component | Specification | Quantity | Approx. Cost | Notes |
|---|---|---|---|---|
| TEC1 Peltier Cooler | TEC1-12706 or similar, 12V 6A max | 1 | $5-10 | 40×40mm standard size |
| Cooler MOSFET | IRFZ44N or IRLZ44N, N-channel | 1 | $1-3 | Same as heater, logic-level |
| MOSFET Gate Resistor | 10kΩ, 1/4W | 1 | $0.10 | Pull-down for safety |
| Flyback Diode | 1N5408 or similar, 3A | 1 | $0.50 | Higher current for Peltier |
| Heat Sink (Cold Side) | Aluminum, small | 1 | $3-8 | Required for efficient cooling |
| Heat Sink (Hot Side) | Aluminum with fan (optional) | 1 | $5-15 | Fan highly recommended for heat dissipation |
| Thermal Paste | High-conductivity, 1-2g syringe | 1 | $3-6 | Critical for Peltier performance |
| Cooling Fan (optional) | 12V, 40×40mm or 60×60mm | 1 | $3-8 | Improves hot-side heat removal |

**Subtotal: $21-50**

---

## 3. Stimulus Delivery System

### Optical Stimulus (LED)

| Component | Specification | Quantity | Approx. Cost | Notes |
|---|---|---|---|---|
| High-Brightness White LED | 5mm or 10mm, 20-50mA, white | 1-3 | $1-3 | 3-5V forward voltage |
| LED Driver MOSFET | 2N7000 or BS170, N-channel | 1 | $0.50-1 | Small signal MOSFET sufficient |
| Current-Limiting Resistor | 100-330Ω, 1/4W | 1 | $0.10 | Calculate for 20-30mA |
| LED Mounting | Holder or custom bracket | 1 | $1-3 | Position for uniform illumination |

**Subtotal: $3-8**
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

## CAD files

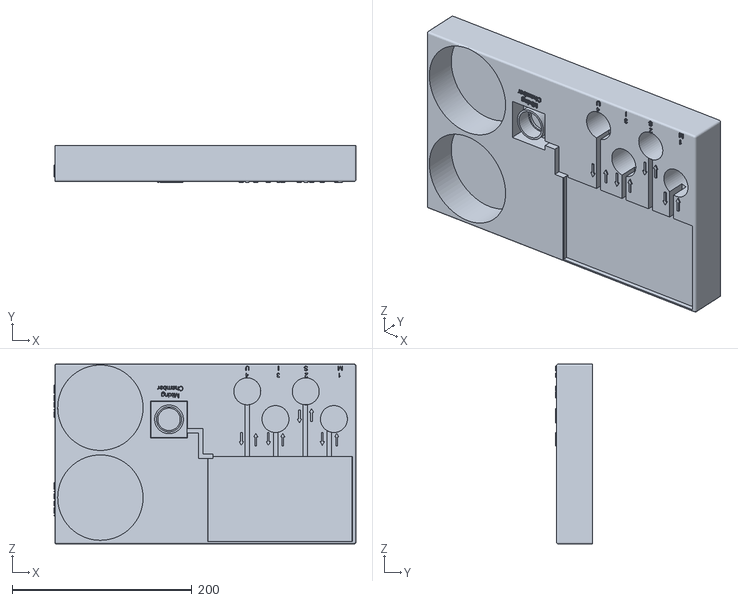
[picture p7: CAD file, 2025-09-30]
Microscope_mounted_chemostat/Hardware/3D_Models/MCMC pump table.stl
336.0 x 41.0 x 200.0

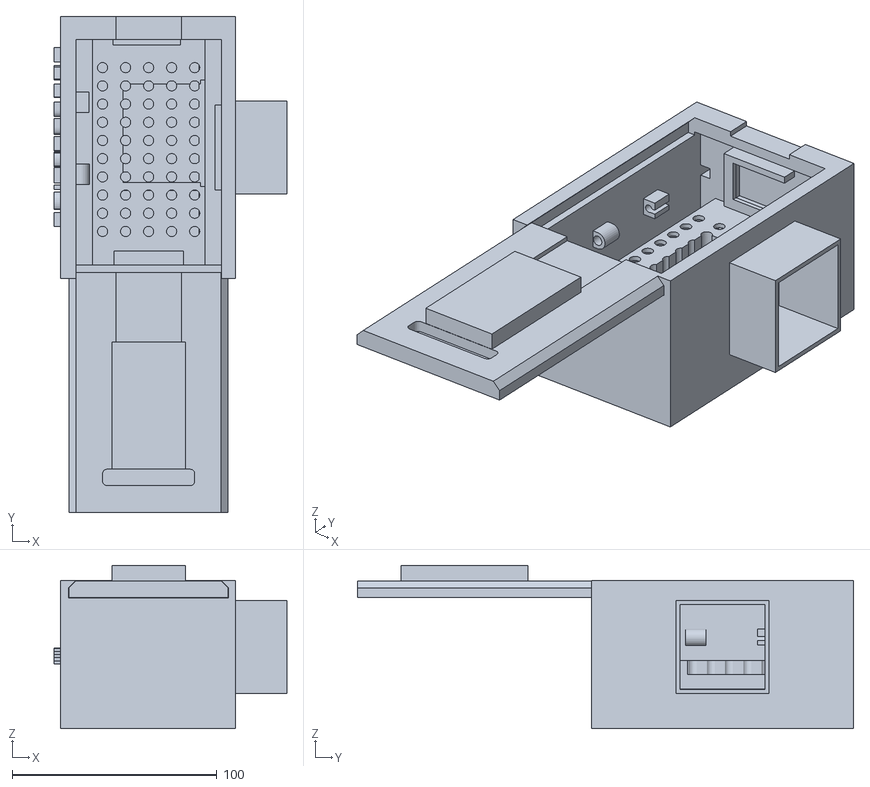
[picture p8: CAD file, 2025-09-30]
Smart_incubator/Hardware/3D_Models/Single flask box newest correct distences Big Palteir v3.stl
113.6 x 242.3 x 79.6

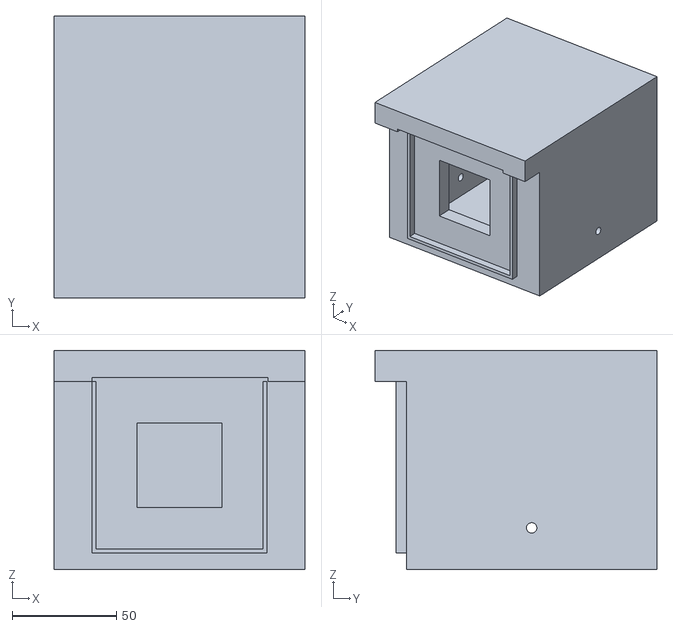
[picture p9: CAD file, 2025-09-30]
Microscope_mounted_chemostat/Hardware/3D_Models/MCMC Temp control box.stl
120.0 x 135.0 x 105.0

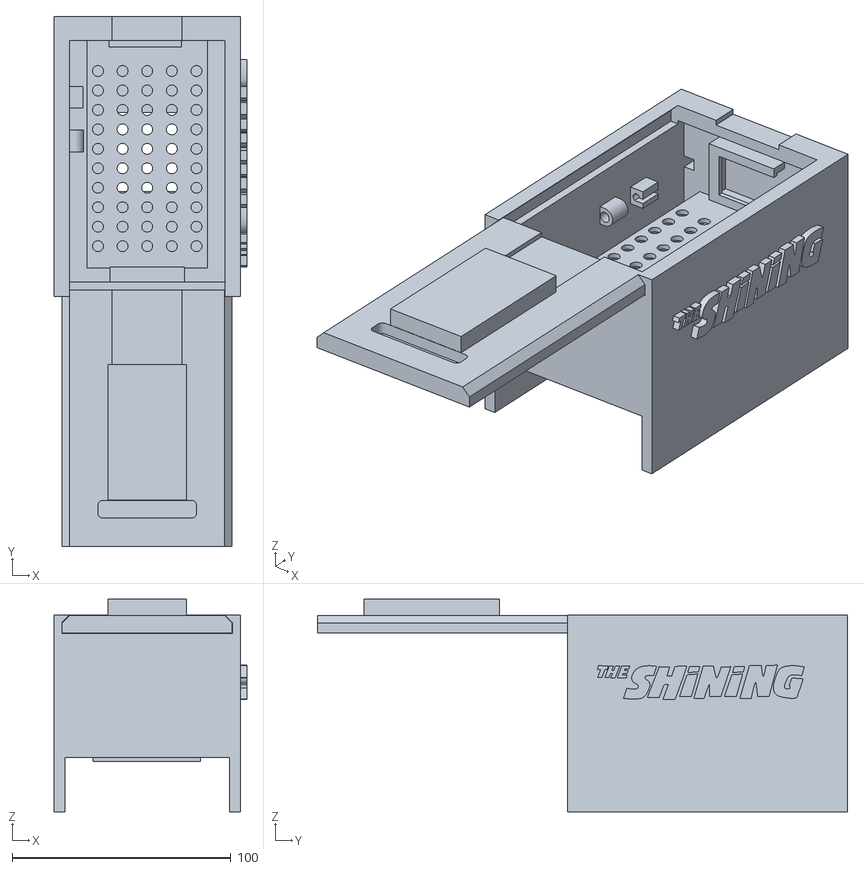
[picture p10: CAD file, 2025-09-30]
Smart_incubator/Hardware/3D_Models/Single flask box v9.stl
88.0 x 242.3 x 97.3

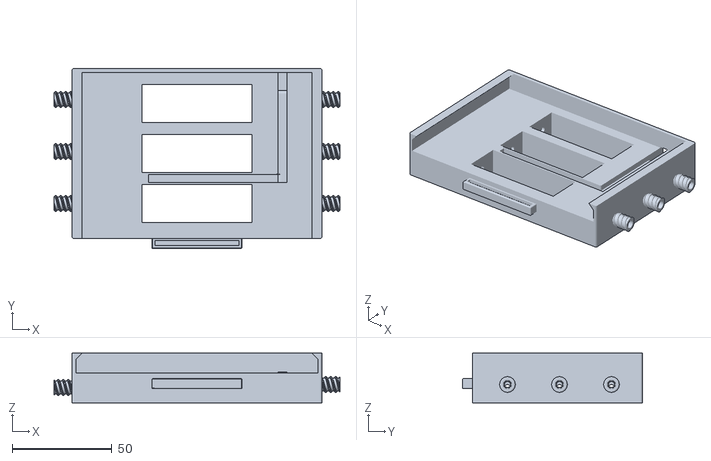
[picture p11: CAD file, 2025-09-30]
Microscope_mounted_chemostat/Hardware/3D_Models/Multi channel chemostat v5 BOX.stl
143.0 x 90.0 x 25.0

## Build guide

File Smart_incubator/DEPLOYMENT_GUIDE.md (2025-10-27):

# Smart Incubator Deployment Guide

## Quick Start: Choose Your Method

### Method 1: Intelligent Sync (⭐ Recommended)
**Auto-detects changes and only uploads modified files**

```bash
# First time (blank ESP32): Installs packages & uploads everything
python3 Smart_incubator/sync_firmware.py

# Subsequent runs: Only syncs changed files
python3 Smart_incubator/sync_firmware.py

# Force complete reinstall (if needed)
python3 Smart_incubator/sync_firmware.py --force
```

**How it works:**
- 🆕 **First Run (Blank ESP32):**
  1. Detects no firmware present
  2. Installs required MicroPython packages
  3. Creates SD card directory structure
  4. Uploads ALL firmware files
  5. Uploads ALL config files
  6. Marks ESP32 as initialized

- 🔄 **Subsequent Runs:**
  1. Checks file hashes against cache
  2. Only uploads changed files
  3. Updates cache

**Advantages:**
- ✅ Handles blank ESP32 automatically
- ✅ Only uploads changed files (fast!)
- ✅ Auto-detects ESP32 port
- ✅ Maintains deployment cache
- ✅ No manual tracking needed

---

### Method 2: VS Code Tasks (⭐⭐ Best for Development)
**One-click deployment from VS Code**

1. Press `Cmd+Shift+P` (Mac) or `Ctrl+Shift+P` (Windows/Linux)
2. Type "Tasks: Run Task"
3. Choose:
   - **Sync Firmware (Auto)** - Smart sync (recommended)
   - **Deploy Core HES Modules** - Only HES files
   - **Deploy Full Firmware** - Everything
   - **Deploy Config Files Only** - Just JSON configs
   - **Format SD Card** - ⚠️ Clear SD card and create fresh structure
   - **Open REPL** - Interactive Python shell
   - **Run Experiment** - Start experiment directly

**Keyboard Shortcut:**
- `Cmd+Shift+B` - Runs default task (Smart Sync)

---

### Method 3: Manual Script
**For when you want control**

```bash
# Core HES modules only
./Smart_incubator/deploy.sh /dev/tty.usbserial-0001 core

# Full firmware update
./Smart_incubator/deploy.sh /dev/tty.usbserial-0001 full

# Config files only
./Smart_incubator/deploy.sh /dev/tty.usbserial-0001 config-only
```

---

### Method 4: Direct mpremote Commands
**For quick single-file updates**

```bash
# Upload single file
mpremote connect /dev/tty.usbserial-0001 cp Firmware/main.py :/main.py

# Upload config
mpremote connect /dev/tty.usbserial-0001 cp Configs/experiment.json :/sd/experiment.json

# Run without uploading (test before deploy)
mpremote connect /dev/tty.usbserial-0001 run test_script.py

# Execute Python command
mpremote connect /dev/tty.usbserial-0001 exec "print('Hello from ESP32!')"
```

---

## Installation: One-Time Setup

### Install Required Tools

```bash
# Install Python tools
pip install mpremote adafruit-ampy rshell

# Verify installation
mpremote version
ampy --help
rshell version
```

### Find Your ESP32 Port

**macOS:**
```bash
ls /dev/tty.usbserial* /dev/tty.SLAB_USBtoUART
# Output: /dev/tty.usbserial-0001
```

**Linux:**
```bash
ls /dev/ttyUSB* /dev/ttyACM*
# Output: /dev/ttyUSB0
```

**Windows:**
```bash
# Use Device Manager or:
mode
# Output: COM3, COM4, etc.
```

---

## Common Workflows

### Workflow 0: Format SD Card for New Experiment

**⚠️ Warning: This deletes all existing experiment data!**

```bash
# Method 1: Using the script (auto-detects port)
python3 Smart_incubator/format_sd_card.py

# Method 2: Using VS Code task
# Press Cmd+Shift+P → "Tasks: Run Task" → "Format SD Card"

# Method 3: Manual port specification
python3 Smart_incubator/format_sd_card.py /dev/tty.usbserial-0001
```

**What it does:**
- 🗑️ Removes all experiment data from `/sd/data/`
- 🗑️ Removes all config files from `/sd/`
- 📁 Creates fresh directory structure:
  - `/sd/data/markovian_experiments/`
  - `/sd/configs_backup/`
- ✅ Keeps system files intact (boot.py, main.py, etc.)
- 📊 Shows storage statistics

**When to use:**
- Starting a new series of experiments
- SD card is full of old data
- Corrupted experiment files
- Want a clean slate

**Safety features:**
- Requires typing "YES" twice to confirm
- Shows what will be deleted before proceeding
- Auto-detects ESP32 port
- Verifies SD card is accessible

---

### Workflow 1: Brand New ESP32 Setup

```bash
# 1. Flash MicroPython firmware (one time)
esptool.py --port /dev/tty.usbserial-0001 erase_flash
esptool.py --port /dev/tty.usbserial-0001 write_flash -z 0x1000 esp32-micropython.bin

# 2. Run sync script (auto-detects blank ESP32)
python3 Smart_incubator/sync_firmware.py

# Output will show:
# 🆕 FIRST TIME SETUP DETECTED
# 📦 Installing MicroPython packages...
# 📁 Creating SD card directories...
# 📤 Uploading ALL firmware files...
# ✅ Initial deployment complete!

# 3. Test
mpremote connect /dev/tty.usbserial-0001 repl
>>> import markovian_hes_executor
>>> # Success!
```

### Workflow 2: Daily Development Cycle

```bash
# 1. Edit files in VS Code
# 2. Press Cmd+Shift+B (auto-sync changed files)
# 3. Press Cmd+Shift+P → "Tasks: Run Task" → "Open REPL"
# 4. Test in REPL:
>>> import markovian_hes_executor
>>> markovian_hes_executor.run_experiment('/sd/test.json')
```

### Workflow 3: Deploy New Experiment

```bash
# 1. Create config file: Configs/my_experiment.json
# 2. Deploy config only:
./Smart_incubator/deploy.sh /dev/tty.usbserial-0001 config-only

# 3. Run via VS Code task "Run Experiment"
# Or manually:
mpremote connect /dev/tty.usbserial-0001 exec "import markovian_hes_executor; markovian_hes_executor.run_experiment('/sd/my_experiment.json')"
```

### Workflow 3: Debug Issue on Device

```bash
# 1. Connect to REPL
mpremote connect /dev/tty.usbserial-0001 repl

# 2. In REPL:
>>> import os
>>> os.listdir('/')           # List root files
>>> os.listdir('/sd')          # List SD card files

# 3. Check logs
>>> with open('/sd/data/latest_experiment/hes_sequence.json') as f:
...     print(f.read())

# 4. Test individual module
>>> import hes_config_loader
>>> config = hes_config_loader.load_config('/sd/test.json')
>>> print(config)
```

### Workflow 4: Debug Issue on Device

```bash
# 1. Connect to REPL
mpremote connect /dev/tty.usbserial-0001 repl

# 2. In REPL:
>>> import os
>>> os.listdir('/')           # List root files
>>> os.listdir('/sd')          # List SD card files

# 3. Check logs
>>> with open('/sd/data/latest_experiment/hes_sequence.json') as f:
...     print(f.read())

# 4. Test individual module
>>> import hes_config_loader
>>> config = hes_config_loader.load_config('/sd/test.json')
>>> print(config)
```

### Workflow 5: Reset Everything (Corrupt Firmware)

```bash
# 1. Force complete reinstall
python3 Smart_incubator/sync_firmware.py --force

# This will:
# - Clear deployment cache
# - Reinstall all packages
# - Re-upload all files
# - Recreate directories

# 2. Or manually erase and start fresh:
# Erase all files
mpremote connect /dev/tty.usbserial-0001 exec "import os; [os.remove(f) for f in os.listdir('/') if f.endswith('.py')]"

# Deploy fresh firmware
./Smart_incubator/deploy.sh /dev/tty.usbserial-0001 full

# Reset device
mpremote connect /dev/tty.usbserial-0001 reset
```

---

## Advanced Features

### Mount Local Filesystem (⭐ AMAZING!)

```bash
# Your local files appear on the ESP32!
mpremote connect /dev/tty.usbserial-0001 mount Smart_incubator/Firmware

# Now in REPL:
>>> import markovian_hes_executor  # Runs from YOUR computer!
```

**Use case:** Rapid development without uploading

### Auto-Run on Boot

Edit `boot.py`:
```python
# boot.py
import markovian_hes_executor
markovian_hes_executor.run_experiment('/sd/auto_experiment.json')
```

Deploy:
```bash
mpremote connect /dev/tty.usbserial-0001 cp Firmware/boot.py :/boot.py
mpremote connect /dev/tty.usbserial-0001 reset
```

### Continuous Sync (Watch Mode)

```bash
# Install watchdog
pip install watchdog

# Run auto-sync on file changes
python3 -c "
import time
from watchdog.observers import Observer
from watchdog.events import FileSystemEventHandler
import subprocess

class SyncHandler(FileSystemEventHandler):
    def on_modified(self, event):
        if event.src_path.endswith('.py'):
            print(f'🔄 Detected change: {event.src_path}')
            subprocess.run(['python3', 'Smart_incubator/sync_firmware.py'])

observer = Observer()
observer.schedule(SyncHandler(), 'Smart_incubator/Firmware', recursive=True)
observer.start()
print('👀 Watching for changes... (Ctrl+C to stop)')
try:
    while True:
        time.sleep(1)
except KeyboardInterrupt:
    observer.stop()
observer.join()
"
```

---

## Troubleshooting

### Issue: Port Not Found
```bash
# Check USB connection
ls /dev/tty.* 

# Check drivers (macOS/Linux)
# May need CH340 or CP2102 drivers

# Windows: Install USB-to-Serial drivers from manufacturer
```

### Issue: Permission Denied (Linux)
```bash
# Add user to dialout group
sudo usermod -a -G dialout $USER
# Log out and back in

# Or use sudo
sudo mpremote connect /dev/ttyUSB0 ls
```

### Issue: Upload Fails
```bash
# 1. Reset device first
mpremote connect /dev/tty.usbserial-0001 reset

# 2. Wait 3 seconds, then upload
sleep 3 && mpremote connect /dev/tty.usbserial-0001 cp file.py :/

# 3. If still fails, erase flash and re-flash MicroPython
esptool.py --port /dev/tty.usbserial-0001 erase_flash
esptool.py --port /dev/tty.usbserial-0001 write_flash -z 0x1000 esp32-micropython.bin
```

### Issue: Out of Memory
```bash
# Check free space
mpremote connect /dev/tty.usbserial-0001 exec "import os; print(os.statvfs('/'))"

# Remove old files
mpremote connect /dev/tty.usbserial-0001 exec "import os; os.remove('/old_file.py')"

# Or use compiled .mpy files (smaller)
mpy-cross Firmware/markovian_hes_executor.py
mpremote connect /dev/tty.usbserial-0001 cp markovian_hes_executor.mpy :/
```

---

## File Structure on ESP32

```
/                           # Root filesystem (flash)
├── boot.py                 # Runs on every boot
├── main.py                 # Runs after boot.py
├── markovian_hes_executor.py
├── hes_config_loader.py
├── hes_transition_engine.py
├── hes_actuator_controller.py
├── hes_logger.py
├── temp_controller.py
├── led_control.py
└── ... (other firmware files)

/sd/                        # SD card
├── experiment.json         # Config files
├── test_config.json
└── data/                   # Experiment data
    └── 20251014_143022_Experiment/
        ├── config.json
        ├── hes_sequence.json
        ├── actuator_timeseries.json
        └── ...
```

---

## Quick Reference Card

| Task | Command |
|---|---|
| **First time setup** | `python3 Smart_incubator/sync_firmware.py` |
| **Smart sync** | `python3 Smart_incubator/sync_firmware.py` |
| **Force reinstall** | `python3 Smart_incubator/sync_firmware.py --force` |
| **Format SD card** | `python3 Smart_incubator/format_sd_card.py` |
| **VS Code deploy** | `Cmd+Shift+B` |
| **VS Code format SD** | `Cmd+Shift+P` → Tasks → Format SD Card |
| **Upload file** | `mpremote connect PORT cp local.py :/remote.py` |
| **Open REPL** | `mpremote connect PORT repl` |
| **List files** | `mpremote connect PORT ls` |
| **Run script** | `mpremote connect PORT run script.py` |
| **Execute command** | `mpremote connect PORT exec "print('hi')"` |
| **Reset device** | `mpremote connect PORT reset` |
| **Mount filesystem** | `mpremote connect PORT mount .` |

---

## Next Steps

### For Brand New ESP32:
1. **Flash MicroPython:** `esptool.py --port PORT erase_flash && esptool.py --port PORT write_flash -z 0x1000 firmware.bin`
2. **Initial setup:** `python3 Smart_incubator/sync_firmware.py`
3. **Test:** `mpremote connect PORT repl`

### For Existing ESP32:
1. **Install tools:** `pip install mpremote`
2. **Find port:** `ls /dev/tty.*`
3. **Sync changes:** Press `Cmd+Shift+B` in VS Code

**Happy coding! 🚀**

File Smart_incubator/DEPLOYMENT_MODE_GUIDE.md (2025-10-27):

# Deployment Mode Guide

## Problem Solved

**Issue**: Your ESP32's `boot.py` automatically runs `main.py` on startup, making it difficult to update firmware files because the running program blocks file transfers.

**Solution**: A deployment mode system that temporarily prevents auto-start during updates.

## How It Works

### The Mechanism

Your `boot.py` already includes a built-in deployment mode check:

```python
# In boot.py
if 'deployment_mode' in os.listdir('/'):
    print("=== DEPLOYMENT MODE ===")
    print("Main program will NOT auto-run")
    # Stays in REPL, doesn't run main.py
else:
    # Normal operation: runs main.py
    import main
    main.main()
```

When a file called `/deployment_mode` exists on the ESP32, `main.py` won't auto-run, allowing safe file updates.

## Using the Deployment System

### Method 1: Automatic (Recommended)

The `sync_firmware.py` script now automatically manages deployment mode:

```bash
python3 Smart_incubator/sync_firmware.py
```

**What happens:**
1. Script detects ESP32 and enables deployment mode
2. Attempts soft reset (or prompts for manual reset)
3. Uploads changed files safely
4. Asks if you want to disable deployment mode
5. If disabled, device will auto-run on next boot

### Method 2: Manual Toggle

Use the dedicated toggle script:

```bash
python3 Smart_incubator/toggle_deployment_mode.py
```

This interactive tool lets you:
- Check current deployment mode status
- Enable deployment mode (prevent auto-run)
- Disable deployment mode (allow auto-run)

### Method 3: Direct Commands

Enable deployment mode:
```bash
mpremote connect /dev/tty.YOUR_PORT exec "f = open('/deployment_mode', 'w'); f.write('SAFE'); f.close()"
```

Disable deployment mode:
```bash
mpremote connect /dev/tty.YOUR_PORT exec "import os; os.remove('/deployment_mode')"
```

Check status:
```bash
mpremote connect /dev/tty.YOUR_PORT exec "import os; print('deployment_mode' in os.listdir('/'))"
```

## Workflow Examples

### Example 1: Quick Update

```bash
# Run sync - it handles everything
python3 Smart_incubator/sync_firmware.py

# When prompted, choose 'Y' to disable deployment mode
# Device will auto-run on next reset
```

### Example 2: Development Session

```bash
# Enable deployment mode for extended development
python3 Smart_incubator/toggle_deployment_mode.py
# Choose "1" to enable

# Now you can freely update files
python3 Smart_incubator/sync_firmware.py
# Choose 'n' to keep deployment mode enabled

# Make more changes, run sync again...

# When done, disable deployment mode
python3 Smart_incubator/toggle_deployment_mode.py
# Choose "1" to disable

# Reset device to start auto-run
mpremote connect /dev/tty.YOUR_PORT reset
```

### Example 3: Emergency Manual Control

If your device is stuck or you need manual control:

```bash
# 1. Enable deployment mode remotely
mpremote connect /dev/tty.YOUR_PORT exec "f = open('/deployment_mode', 'w'); f.write('SAFE'); f.close()"

# 2. Reset device
# Press the EN button on your ESP32

# 3. Device boots but won't run main.py
# You can now safely update files

# 4. When done, disable deployment mode
mpremote connect /dev/tty.YOUR_PORT exec "import os; os.remove('/deployment_mode')"

# 5. Reset again to start normal operation
```

## Understanding the States

### Deployment Mode ENABLED
- **Status**: `/deployment_mode` file exists on device
- **Behavior**: `boot.py` runs, but `main.py` does NOT auto-run
- **Use case**: Safe for file updates, development, debugging
- **REPL access**: Available immediately after boot

### Deployment Mode DISABLED
- **Status**: `/deployment_mode` file does NOT exist
- **Behavior**: `boot.py` runs, then automatically runs `main.py`
- **Use case**: Normal operation, production use
- **REPL access**: Only available if main.py exits or crashes

## Troubleshooting

### Problem: Can't Upload Files

**Solution**: Enable deployment mode first
```bash
python3 Smart_incubator/toggle_deployment_mode.py
# Choose option to enable
# Then reset your device (press EN button)
```

### Problem: Device Won't Auto-Run After Update

**Cause**: Deployment mode is still enabled

**Solution**: Disable deployment mode
```bash
python3 Smart_incubator/toggle_deployment_mode.py
# Choose option to disable
# Then reset your device
```

### Problem: Script Says "Device May Be Running"

**Solution**: Manually reset the device
1. Press the EN (reset) button on your ESP32
2. Wait 2-3 seconds
3. Press Enter in the terminal to continue

### Problem: Lost REPL Access

If deployment mode is disabled and main.py is running:

**Option 1**: Enable deployment mode remotely, then reset
```bash
mpremote connect /dev/tty.YOUR_PORT exec "f = open('/deployment_mode', 'w'); f.write('SAFE'); f.close()"
# Press EN button on device
```

**Option 2**: Use Ctrl+C in REPL to interrupt
```bash
mpremote connect /dev/tty.YOUR_PORT repl
# Press Ctrl+C to interrupt
```

## Best Practices

1. **During Development**: Keep deployment mode ENABLED
   - Prevents accidental auto-starts
   - Makes testing easier
   - Safer file updates

2. **For Production**: Keep deployment mode DISABLED
   - Device auto-starts on power cycle
   - Runs autonomously
   - Survives power outages

3. **Before Long-Running Experiments**: Disable deployment mode
   - Ensures device restarts properly if power is lost
   - No manual intervention needed

4. **When Troubleshooting**: Enable deployment mode
   - Prevents program from interfering
   - Full REPL access
   - Can test components individually

## Quick Reference

| Action | Command |
|---|---|
| Auto-deploy with management | `python3 Smart_incubator/sync_firmware.py` |
| Interactive toggle | `python3 Smart_incubator/toggle_deployment_mode.py` |
| Enable manually | `mpremote exec "open('/deployment_mode','w').write('SAFE')"` |
| Disable manually | `mpremote exec "import os; os.remove('/deployment_mode')"` |
| Check status | `mpremote exec "import os; print('deployment_mode' in os.listdir('/'))"` |
| Reset device | `mpremote reset` or press EN button |

## Integration with Existing Tools

The deployment mode system is now integrated into:
- ✅ `sync_firmware.py` - Automatic management
- ✅ `toggle_deployment_mode.py` - Manual control
- ✅ `boot.py` - Built-in detection
- 🔄 Compatible with all existing mpremote commands

You can still use all your existing deployment scripts; they'll work better now with deployment mode protection!

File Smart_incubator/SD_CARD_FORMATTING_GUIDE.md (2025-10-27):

# SD Card Formatting Guide

Quick guide for formatting SD cards for Smart Incubator experiments.

---

## 🎯 Which Method Should I Use?

| Scenario | Method | Command |
|---|---|---|
| **New SD card** | Local formatter | `python3 format_sd_card_local.py --list` |
| **SD card needs reformat** | Local formatter | `python3 format_sd_card_local.py /dev/diskX` |
| **SD card already in ESP32** | ESP32 formatter | `python3 format_sd_card.py` |
| **Quick cleanup** | ESP32 formatter | `python3 format_sd_card.py` |
| **File system corruption** | Local formatter | `python3 format_sd_card_local.py /dev/diskX` |

---

## Method 1: Format SD Card in Computer (Recommended for New Cards)

**Best for:** Brand new SD cards, corrupted file systems, complete reformats

### Step 1: Insert SD Card
Insert SD card into your computer's SD card reader.

### Step 2: List Available Disks
```bash
cd Smart_incubator
python3 format_sd_card_local.py --list
```

**macOS Output Example:**
```
/dev/disk0 (internal, physical) - YOUR SYSTEM DISK - DON'T FORMAT!
/dev/disk3 (synthesized) - YOUR SYSTEM VOLUME - DON'T FORMAT!
/dev/disk4 (external, physical) - SD CARD - THIS IS IT!
   #:                       TYPE NAME                    SIZE       IDENTIFIER
   0:     FDisk_partition_scheme                        *32.0 GB    disk4
   1:                 DOS_FAT_32 UNTITLED                32.0 GB    disk4s1
```

⚠️ **IMPORTANT:** SD cards are usually:
- macOS: `/dev/disk4` or higher (NOT disk0, disk1, disk2, disk3)
- Linux: `/dev/sdb`, `/dev/sdc` (NOT /dev/sda)

### Step 3: Format the SD Card
```bash
# macOS example
python3 format_sd_card_local.py /dev/disk4

# Linux example  
python3 format_sd_card_local.py /dev/sdb
```

**The script will:**
1. Show disk information
2. Ask for confirmation (type `YES`)
3. Unmount the disk
4. Format as FAT32 (DOS_FAT_32) with MBR
5. Create directory structure:
   - `/data/markovian_experiments/`
   - `/configs_backup/`
6. Show storage statistics

### Step 4: Eject Safely
```bash
# macOS
diskutil eject /dev/disk4

# Linux
sudo eject /dev/sdb
```

### Step 5: Insert into ESP32
- Remove SD card from computer
- Insert into ESP32 SD card module
- Ready to deploy firmware!

---

## Method 2: Format SD Card via ESP32

**Best for:** SD card already in ESP32, quick cleanup, remote formatting

### Requirements
- SD card inserted in ESP32
- ESP32 connected via USB
- ESP32 has firmware deployed

### Steps
```bash
cd Smart_incubator

# Auto-detect ESP32 port
python3 format_sd_card.py

# Or specify port
python3 format_sd_card.py /dev/tty.usbserial-0001
```

**The script will:**
1. Check SD card is accessible
2. List existing experiment data
3. Ask for confirmation (type `YES` **twice**)
4. Delete all data and configs
5. Create fresh directory structure
6. Show storage statistics

**Note:** This method does NOT reformat the filesystem - it only clears files and recreates directories. For complete reformatting, use Method 1.

---

## 📋 After Formatting

### Deploy Firmware
```bash
# Sync firmware to ESP32
python3 sync_firmware.py

# Or use VS Code
# Press Cmd+Shift+B
```

### Copy Config Files
```bash
# Via mpremote (if SD card in ESP32)
mpremote connect PORT cp Configs/experiment.json :/sd/experiment.json

# Or via sync script (will detect new configs)
python3 sync_firmware.py
```

### Test SD Card
```bash
# Connect to REPL
mpremote connect PORT repl

# In REPL, test SD access:
>>> import os
>>> os.listdir('/sd')
['data', 'configs_backup']
>>> os.listdir('/sd/data')
['markovian_experiments']
```

---

## 🆘 Troubleshooting

### "Disk not found" (Local Format)
```bash
# Make sure SD card is inserted
# Run list command to see all disks
python3 format_sd_card_local.py --list

# Check physical connection
# Try reinserting SD card
```

### "Permission denied" (Linux)
```bash
# Use sudo for formatting operations
sudo python3 format_sd_card_local.py /dev/sdb

# Or add user to disk group
sudo usermod -a -G disk $USER
# Log out and back in
```

### "SD card not accessible" (ESP32 Format)
```bash
# Check SD card is inserted properly
# Verify SD card module is working

# Test in REPL:
>>> import os
>>> os.listdir('/')
# Should show 'sd' if SD card is mounted

# If not mounted, check wiring and sdcard.py module
```

### "Format failed" (Local)
```bash
# Disk may be in use
# Close any programs accessing the SD card
# Unmount manually:

# macOS
diskutil unmountDisk /dev/disk4

# Linux
sudo umount /dev/sdb1
sudo umount /dev/sdb2
```

### SD Card Not Recognized by ESP32
```bash
# SD card must be FAT32 (not exFAT or NTFS)
# Use local formatter to ensure correct format

# Check SD card is not too large (max 32GB for FAT32)
# For larger cards, use exFAT support or partition
```

---

## 💡 Pro Tips

1. **Always use `--list` first** - Double-check disk before formatting
2. **Label your SD cards** - Write "ESP32-1", "ESP32-2" on cards
3. **Keep spare formatted SD cards** - Quick swaps for experiments
4. **Backup experiment data** - Copy `/sd/data/` before formatting
5. **Use quality SD cards** - Cheap cards fail more often
6. **Format on computer when possible** - More reliable than ESP32 formatting
7. **Check filesystem regularly** - Run filesystem check on computer monthly

---

## 📊 Recommended SD Card Specs

- **Capacity:** 4GB - 32GB (FAT32 limit)
- **Class:** Class 10 or UHS-I
- **Brand:** SanDisk, Samsung, Kingston (reliable brands)
- **Format:** FAT32 (DOS_FAT_32)
- **Partition:** MBR (not GPT)

---

## 🔗 Related Documentation

- [DEPLOYMENT_GUIDE.md](DEPLOYMENT_GUIDE.md) - Complete deployment workflow
- [DEPLOYMENT_TOOLS_SUMMARY.md](DEPLOYMENT_TOOLS_SUMMARY.md) - All tools reference
- [QUICK_START.md](QUICK_START.md) - Visual workflow guides

---

**Ready to format? 💾**

**Method 1 (Local):**
```bash
python3 Smart_incubator/format_sd_card_local.py --list
python3 Smart_incubator/format_sd_card_local.py /dev/diskX
```

**Method 2 (ESP32):**
```bash
python3 Smart_incubator/format_sd_card.py
```

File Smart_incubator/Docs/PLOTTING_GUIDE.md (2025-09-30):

# Smart Incubator Data Analysis Guide

## Overview

After completing your comprehensive analysis of your Smart Incubator codebase, I've created a powerful data analysis and plotting script that understands your specific data structure and experimental protocols.

## Your System Architecture (Summary)

Your Smart Incubator is a **sophisticated biological experimentation platform** featuring:

### Core Components:
- **PID Temperature Control**: Precise dual-actuator system (PTC heater + TEC cooler)
- **Multi-Modal Stimuli**: LED and vibration with configurable timing (20s ON, 60s OFF)
- **Advanced Data Logging**: JSON-based with SHA-256 checksums and manifests
- **Correlation-Based Protocols**: 4 different stimulus-heat shock timing relationships
- **Noise-Filtered Sensing**: Median filtering and validation for temperature readings
- **Failsafe Systems**: Temperature limits, sensor recovery, emergency shutdown

### Data Structure Understanding:
- **Experiments**: Stored in `/sd/data/[DDMMYYYY_correlation]/`
- **Snapshots**: Every 10 seconds with temp, setpoint, power, US activity, phase
- **Cycles**: 200-400 minute random duration with basal→heat shock phases
- **Correlation Modes**:
  - **0**: Random independent timing
  - **1**: US precedes heat shock (DEFAULT)
  - **2**: US follows heat shock  
  - **3**: Testing mode (early stimuli)

## Installation

1. **Install Python dependencies**:
   ```bash
   pip install -r requirements_plotting.txt
   ```

2. **Copy your SD card data** to your computer:
   ```bash
   # Example: copy from SD card to local directory
   cp -r /Volumes/INCUBATOR/data ./incubator_data/
   ```

## Usage Examples

### Basic Usage (Auto-select most recent experiment):
```bash
python plot_experiment_data.py ./incubator_data/
```

### Analyze specific experiment:
```bash
python plot_experiment_data.py ./incubator_data/ --experiment 9298_1
```

### Analyze specific cycles only:
```bash
python plot_experiment_data.py ./incubator_data/ --experiment 9298_1 --cycles 1-5
```

### Generate comprehensive report:
```bash
python plot_experiment_data.py ./incubator_data/ --experiment 9298_1 --report --output ./analysis_results/
```

## Plot Types Generated

### 1. **Temperature Overview**
**What it shows**: Complete thermal profile with correlation to baseline and heat shock
- **Top panel**: Temperature vs time with basal (23°C) and heat shock (32°C) reference lines
- **Middle panel**: Power output (heating/cooling) and US stimulus activity
- **Bottom panel**: Experiment phases (basal vs heat shock)

**Key Insights**:
- Temperature regulation precision
- Heat shock timing and effectiveness
- US stimulus patterns in relation to thermal phases

### 2. **Correlation Analysis** 
**What it shows**: Statistical relationship between temperature, US activity, and baseline
- **Temperature deviation histograms**: US active vs inactive periods
- **Scatter plot**: Temperature over time colored by US activity
- **Power distribution**: Heating vs cooling effort analysis
- **Phase analysis**: Average temperatures by experiment phase and US state

**Key Insights**:
- Quantitative effect of US stimulation on temperature
- Control system performance during different phases
- Statistical significance of stimulus-temperature correlations

### 3. **Cycle Comparison**
**What it shows**: Side-by-side comparison of multiple experimental cycles
- **Temperature profiles**: Overlay of all cycle temperature traces
- **US activity patterns**: Stacked visualization of stimulus timing

**Key Insights**:
- Experimental consistency across cycles
- Variation in thermal responses
- US timing pattern reliability

## Data Analysis Features

### Automatic Discovery
The script automatically:
- Finds all experiments in your data directory
- Counts cycles per experiment
- Loads experimental parameters from meta.json files

### Statistical Analysis
Provides quantitative metrics:
- **Temperature Statistics**: Mean temps during US active/inactive periods
- **Correlation Strength**: Temperature difference with/without US
- **Control Performance**: Power distribution, regulation precision
- **Experimental Coverage**: Data point counts, error rates

### Flexible Data Handling
- **Missing Data**: Gracefully handles incomplete datasets
- **Time Alignment**: Works with both elapsed_minutes and timestamp data
- **Multi-Cycle**: Supports single cycle or cycle range analysis
- **Export Options**: High-resolution PNG output for publications

## Understanding Your Experimental Data

### Temperature Fields:
- **`temp`**: Actual measured temperature (°C)
- **`set_temp`**: Target temperature (basal or heat shock)
- **`temp_deviation_basal`**: Difference from basal temperature

### Control Fields:
- **`power`**: PID output (-100 to +100%, negative = cooling)
- **`mode`**: "Heating", "Cooling", or "Idle"
- **`phase`**: "basal" or "heat_shock"

### Stimulus Fields:
- **`us_active`**: 1 if US active, 0 if inactive
- **`us_type`**: "LED", "VIB", or "BOTH"

### Timing Fields:
- **`elapsed_minutes`**: Time from cycle start
- **`cycle_length`**: Total cycle duration (200-400 min)

## Correlation Mode Analysis

Your system supports 4 correlation modes that define stimulus-heat shock timing:

### Mode 0: Random Independent
- US and heat shock occur at random times
- Tests independence of thermal and stimulus effects

### Mode 1: US Precedes Heat Shock (DEFAULT)
- US activates just before heat shock at cycle end
- Tests preparatory/priming effects

### Mode 2: US Follows Heat Shock  
- US activates immediately after heat shock
- Tests recovery/response modulation effects

### Mode 3: Testing Mode
- Early timing (heat at 1min, US at 0.5min)
- For system validation and rapid testing

## Troubleshooting

### Common Issues:

1. **"No experiments found"**
   - Check data directory path
   - Ensure meta.json files exist in experiment directories

2. **"Experiment not found"**  
   - List available experiments first: `python plot_experiment_data.py ./data/ --help`
   - Use exact experiment ID format: `DDMMYYYY_correlation`

3. **Missing data fields**
   - Script gracefully handles missing fields
   - Check your JSON data structure matches expected format

4. **Empty plots**
   - Ensure cycle data files exist (cycle_N_TIMESTAMP.json)
   - Check that cycle range matches available data

### Data Validation:
Before running analysis, you can validate your data structure:
```bash
# Check experiment structure
ls -la ./incubator_data/9298_1/
# Should show: meta.json, manifest.json, cycle_*.json files

# Verify JSON format
python -m json.tool ./incubator_data/9298_1/meta.json
```

## Advanced Usage

### Custom Analysis Scripts
The `IncubatorDataAnalyzer` class can be imported for custom analysis:

```python
from plot_experiment_data import IncubatorDataAnalyzer

# Initialize analyzer
analyzer = IncubatorDataAnalyzer('./incubator_data')

# Load experiment
analyzer.load_experiment('9298_1')

# Get raw cycle data for custom analysis
cycle_data, meta = analyzer.load_cycle_data('9298_1', '1-3')

# Your custom analysis here...
```

### Publication-Ready Plots
For publication-quality figures:
- Use `--report` flag for comprehensive analysis
- Plots saved as 300 DPI PNG files
- Professional styling with seaborn themes
- Clear legends and axis labels

### Batch Analysis
To analyze multiple experiments:
```bash
# Create analysis script for all experiments
for exp in $(ls incubator_data/); do
    python plot_experiment_data.py ./incubator_data/ --experiment $exp --report --output ./results/$exp/
done
```

## Scientific Interpretation

### Expected Results by Correlation Mode:

**Mode 1 (US Precedes Heat Shock)**:
- Should show US activation just before temperature ramp
- Look for potential pre-conditioning effects
- Temperature may show different kinetics compared to no-US periods

**Mode 0 (Random)**:
- Independent US and heat shock timing
- Provides baseline for comparison
- Tests system performance under various conditions

**Modes 2 & 3**:
- Different temporal relationships for mechanistic studies
- Compare response patterns across correlation modes

### Key Metrics to Look For:
1. **Temperature Regulation Precision**: Standard deviation during basal periods
2. **Heat Shock Effectiveness**: Rate and magnitude of temperature increase
3. **US Correlation Effects**: Statistical difference in temperature when US is active
4. **System Stability**: Consistent performance across multiple cycles
5. **Control Effort**: Power distribution patterns during different phases

This analysis framework will help you understand the biological and technical aspects of your Smart Incubator experiments, providing both visual insights and quantitative metrics for scientific interpretation.

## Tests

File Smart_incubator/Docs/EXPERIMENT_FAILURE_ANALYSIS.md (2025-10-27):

# Experiment Failure Analysis - Cycle 8+ Crash

## Date: October 27, 2025

## Problem Summary

An experiment that was expected to run continuously got stuck after cycle 8, despite showing cycle 48 on the display. Analysis of the SD card data revealed critical issues with silent failures in the data logging system.

## Root Causes Identified

### 1. **Silent SD Card Write Failures**
- **Issue**: The `log_snapshot()` and `log_cycle_summary()` functions returned `False` when writes failed, but the main experiment loop **did not check these return values**
- **Impact**: The system continued running for 40+ cycles without saving any data after cycle 8
- **Evidence**: 
  - Only 8,489 JSON files found (up to cycle 8, timestamp 9879)
  - Manifest shows cycle 32+ data
  - Display showed cycle 48
  - Final error: "Too many invalid temperature readings"

### 2. **Memory Buildup in Manifest**
- **Issue**: The manifest file list was limited to 100 entries, but snapshots were logged every 10 seconds
- **Impact**: In a ~300 minute cycle, that's ~1,800 snapshots. The manifest list kept growing in RAM even though it wasn't being written to SD
- **Memory leak**: Each cycle added ~1,800 entries to `self.manifest['files']` list in memory
- **Old code**:
```python
if len(self.manifest['files']) > 100:
    self.manifest['files'] = self.manifest['files'][-100:]
```
This only trimmed when updating manifest, which couldn't happen if writes were failing!

### 3. **Poor Experiment ID Generation**
- **Issue**: Experiment ID was generated as `{timestamp/86400}_{correlation}` which often resulted in `0_0`
- **Impact**: Multiple experiments could overwrite each other, difficult to identify experiments
- **Evidence**: The failed experiment was in folder `0_0`

### 4. **Cascading Failure**
1. SD card write failures started (likely bad SD card)
2. System silently continued without saving data
3. Memory filled up with unsaved manifest entries
4. Temperature sensor SPI bus became unreliable (memory/resource contention)
5. System eventually crashed with "Too many invalid temperature readings"

## Fixes Implemented

### 1. **SD Write Failure Detection & Halt**
Added tracking of consecutive write failures:
```python
self.consecutive_write_failures = 0
self.max_write_failures = 10
self.sd_write_ok = True  # Health flag
```

When failures exceed threshold, the experiment **halts immediately** instead of continuing silently:
```python
if self.consecutive_write_failures >= self.max_write_failures:
    print(f"[CRITICAL] SD card write failures exceeded threshold!")
    self.sd_write_ok = False
```

### 2. **Temperature Sensor Error Handling Improvements**
**Problem**: Temperature errors only stopped the current cycle, then the next cycle would start and fail again.

**Fixes**:
- Changed from `return` to `raise RuntimeError()` when sensor fails - **stops entire experiment**
- Increased error threshold from 5 to 10 failed reads (more tolerant of transient errors)
- Added **gradual error recovery**: errors decrement after successful reads instead of immediate reset
- Better error messages distinguish between transient vs. critical failures
- Propagates sensor fault information from MAX31865 chip

```python
if consecutive_invalid_readings >= max_invalid_readings:
    print("[CRITICAL] Sensor fault detected - stopping experiment for safety")
    raise RuntimeError(f"Temperature sensor fault - {fault}")  # Stops everything
```

**Result**: System now distinguishes between:
- **Transient errors** (occasional bad reads) → uses last valid temp and recovers
- **Persistent errors** (sensor failure) → halts experiment immediately for safety

### 3. **Manifest Memory Management**
- Reduced manifest file list from 100 to **50 entries** (more conservative)
- Added warning when trimming occurs
- Made `_update_manifest()` return success/failure status

### 4. **Better Experiment ID Generation**
New format uses RTC if available: `YYYYMMDD_HHMMSS_corr`
```python
exp_id = f"{dt[0]:04d}{dt[1]:02d}{dt[2]:02d}_{dt[4]:02d}{dt[5]:02d}{dt[6]:02d}_{int(correlation)}"
```
Falls back to timestamp if RTC not available, but much more readable.

### 5. **Main Loop SD Health Checks**
Added pre-cycle health checks:
```python
# CRITICAL: Check SD health before starting cycle
if experiment_logger and not experiment_logger.sd_write_ok:
    print(f"[CRITICAL] SD card is unhealthy - cannot start cycle")
    experiment_logger.finalize_experiment(status='error', error='SD card write failures')
    break
```

### 6. **Memory Monitoring**
Added periodic memory checks:
```python
gc.collect()
free_mem = gc.mem_free()
print(f"[Memory] Free heap: {free_mem} bytes")
if free_mem < 10000:  # Less than 10KB free
    print(f"[WARNING] Low memory detected!")
```

### 7. **Critical Error Propagation**
SD failures now raise exceptions that stop the experiment:
```python
if not experiment_logger.sd_write_ok:
    raise RuntimeError("SD card write failures exceeded threshold - experiment halted for safety")
```

## Recommendations

### Immediate Actions
1. ✅ **Use better quality SD cards** (user mentioned this)
   - Class 10 or better
   - High endurance cards designed for continuous writing
   - Smaller capacity (8-16GB) often more reliable than large cards

2. **Format SD cards properly**
   - Use FAT32 filesystem
   - 4KB allocation unit size
   - Format on the device when possible

### Future Improvements

1. **Add SD card health monitoring**
   - Track write speeds
   - Monitor retry rates
   - Warning system before complete failure

2. **Implement data buffering**
   - Keep last N snapshots in RAM
   - Try to flush when SD recovers
   - Graceful degradation

3. **Add watchdog timer**
   - Reset system if main loop hangs
   - Prevent silent failures

4. **Implement experiment resume capability**
   - Save cycle state periodically
   - Allow experiments to continue after reboot

## Testing Recommendations

Before next experiment:
1. **SD Card Test**: Run a write-intensive test for several hours
2. **Memory Test**: Monitor memory usage over multiple cycles
3. **Failure Recovery Test**: Simulate SD card removal mid-cycle
4. **Long Duration Test**: Run 10+ cycles to verify fixes

## Files Modified

1. `sd_logger.py` - Added failure tracking, better ID generation, memory management
2. `run_experiment_cycle.py` - Added SD health checks, critical error propagation, **temperature error raises exceptions**
3. `main.py` - Added pre-cycle health checks, memory monitoring
4. `temp_controller.py` - **Improved error recovery, increased tolerance, better error messages**

## Summary

The experiment appeared to run for 48 cycles but actually stopped saving data after cycle 8 due to silent SD card failures. The system kept running in memory until resources were exhausted, causing temperature sensor failures. The fixes ensure the experiment **halts immediately** when SD card issues are detected, preventing data loss and unsafe operation.

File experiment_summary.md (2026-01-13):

# Experiment Summary

Date: 2025-12-03 16:29:38.422685

## Overview
| Experiment ID | Correlation | Cycles | Avg Length (min) | Avg HS-US Gap (min) | Total Duration (h) |
|---|---|---|---|---|---|
| 20000101_000006_0 | 0 | 35 | 286.60 +/- 65.41 | -42.46 +/- 83.18 | 168.27 |
| 20000101_000007_1 | 1 | 34 | 294.24 +/- 57.31 | 1.06 +/- 0.36 | 168.69 |

## Detailed Analysis
### Experiment: 20000101_000006_0 (Corr: 0)
- **Folder**: `20000101_000006_0`
- **Total Cycles**: 35
- **Total Duration**: 168.27 hours
- **Cycle Length**: 286.60 +/- 65.41 minutes
- **HS-US Gap**: -42.46 +/- 83.18 minutes
  - *Note: Positive Gap means US ended BEFORE HS started. Negative means Overlap.*
  - Min Gap: -244.83 min
  - Max Gap: 184.40 min

### Experiment: 20000101_000007_1 (Corr: 1)
- **Folder**: `20000101_000007_1`
- **Total Cycles**: 34
- **Total Duration**: 168.69 hours
- **Cycle Length**: 294.24 +/- 57.31 minutes
- **HS-US Gap**: 1.06 +/- 0.36 minutes
  - *Note: Positive Gap means US ended BEFORE HS started. Negative means Overlap.*
  - Min Gap: 0.30 min
  - Max Gap: 1.55 min

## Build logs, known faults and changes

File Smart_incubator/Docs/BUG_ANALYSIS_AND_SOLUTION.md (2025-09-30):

# Critical Bug Analysis & Failsafe Solution

## **Bug Summary**
**Issue**: Temperature sensor got "stuck" at 19.1°C while actual temperature climbed dangerously high, causing system overheating and experiment failure.

**Impact**: Critical safety failure - could have damaged hardware or caused fire hazard.

## **Root Cause Analysis**

### **Most Likely Cause: Sensor Failure with Dangerous Fallback**

The temperature getting "stuck at 19.1°C" while causing overheating indicates a **sensor failure combined with the fallback mechanism**:

1. **MAX31865/PT100 sensor started failing** (returning `None` or invalid readings)
2. **System fell back to `last_valid_temp = 19.1°C`** (from the fallback logic)
3. **PID controller thought temperature was 19.1°C** when it was actually much higher
4. **System continued heating aggressively** trying to reach the setpoint
5. **Real temperature climbed dangerously** while sensor remained "stuck"

### **The Dangerous Code Pattern**
In `temp_controller.py`, this fallback was the problem:
```python
if current_temp is None:
    if last_valid_temp is not None:
        current_temp = last_valid_temp  # DANGEROUS FALLBACK
        print(f"[Controller] Using last valid temperature: {current_temp}°C")
```

### **Other Potential Contributing Factors**
- **SPI bus corruption** between MAX31865 and SD card
- **Loose PT100 RTD connections** causing intermittent failures
- **EMI interference** from PWM affecting sensor readings
- **MAX31865 chip failure** or register corruption

## **Solution Implementation**

### **1. Diagnostic Tool: `sensor_diagnostic.py`**
**Purpose**: Identify the specific cause of sensor failures

**Key Features**:
- **Real-time monitoring** of temperature readings with fault detection
- **Stuck reading detection** - identifies patterns like your 19.1°C bug
- **SPI communication testing** - verifies bus reliability
- **Raw register analysis** - checks MAX31865 chip status
- **Comprehensive reporting** with specific recommendations

**Usage**:
```python
# Run on ESP32 to diagnose sensor issues
import sensor_diagnostic
sensor_diagnostic.run_comprehensive_sensor_test(duration_minutes=10)
```

### **2. Failsafe System: `temperature_failsafe.py`**
**Purpose**: Detect stuck temperatures and prevent overheating

**Critical Safety Features**:
- **Stuck Temperature Detection**: Triggers if temperature stays identical for 2+ minutes
- **Overheating Protection**: Emergency shutdown if temperature > 45°C
- **Pattern Recognition**: Detects suspicious low-temp + high-heater scenarios
- **Multiple Safety Checks**: None readings, rapid temperature rises, abnormal patterns

**Failsafe Thresholds**:
- **Stuck Threshold**: 120 seconds (2 minutes as requested)
- **Max Temperature**: 45.0°C (configurable safety limit)
- **Emergency Actions**: Immediate heater/cooler shutdown + system halt

### **3. Integrated Protection: Enhanced `temp_controller.py`**
**What Changed**:
- **Imported failsafe system** into temperature controller
- **Added real-time safety checks** on every control cycle
- **Implemented emergency shutdown** that stops entire system
- **Enhanced error reporting** with specific failsafe warnings

**New Safety Flow**:
1. Read temperature sensor
2. Calculate PID output
3. **CRITICAL**: Check failsafe conditions
4. If unsafe → Emergency shutdown + system halt
5. If warning → Continue with alert
6. If safe → Normal operation

## **Testing Protocol**

### **Step 1: Run Sensor Diagnostics**
```python
# Upload sensor_diagnostic.py to ESP32 and run:
import sensor_diagnostic

# This will identify if you have the stuck sensor issue
sensor_diagnostic.run_comprehensive_sensor_test(duration_minutes=5)
```

**Expected Output**:
- SPI success rate (should be >95%)
- Temperature stability analysis
- **CRITICAL**: Will detect stuck reading sequences
- Specific recommendations for hardware fixes

### **Step 2: Test Failsafe System**
```python
# Test the failsafe system:
import temperature_failsafe
temperature_failsafe.test_failsafe()
```

**Expected Output**:
- Normal operation test (should pass)
- Stuck temperature test (should trigger failsafe)
- Overheating test (should trigger emergency shutdown)

### **Step 3: Full System Test**
With the updated `temp_controller.py`, run a controlled test:
```python
# Test integrated failsafe protection
import temp_controller
temp_controller.run_test(33, 27)  # Your heater/cooler pins
```

The system will now automatically stop if it detects the same bug pattern.

## **Hardware Inspection Checklist**

Based on the analysis, check these potential hardware issues:

### **1. PT100 RTD Sensor**
- [ ] Check all RTD wire connections (should be tight)
- [ ] Verify RTD resistance (~100Ω at room temperature)
- [ ] Look for damaged/corroded wires
- [ ] Ensure proper 3-wire or 4-wire connection

### **2. MAX31865 Chip**
- [ ] Check SPI connections (pins 5, 12, 13, 14)
- [ ] Verify power supply stability (3.3V)
- [ ] Look for physical damage or overheating
- [ ] Test with multimeter for proper voltages

### **3. EMI/Interference**
- [ ] Separate sensor wires from power wires
- [ ] Check for loose connections causing intermittent faults
- [ ] Verify proper grounding
- [ ] Consider shielded cables for RTD if in noisy environment

### **4. SPI Bus Issues**
- [ ] Check for proper pull-up resistors
- [ ] Verify SD card is not interfering with sensor communication
- [ ] Test with shorter wire lengths
- [ ] Ensure proper timing (baudrate settings)

## **Prevention Strategy**

### **Immediate Actions**
1. **Deploy Updated Code**: Upload all new files to ESP32
2. **Run Diagnostics**: Identify current sensor health
3. **Hardware Inspection**: Check connections based on diagnostic results
4. **Test Failsafe**: Verify protection system works

### **Long-term Monitoring**
1. **Regular Sensor Health Checks**: Run diagnostics monthly
2. **Temperature Trend Analysis**: Watch for gradual sensor degradation  
3. **Backup Sensor**: Consider redundant temperature measurement
4. **Data Integrity**: Monitor for suspicious patterns in logged data

## **Emergency Response Plan**

If the failsafe triggers during an experiment:

### **Immediate Actions**
1. **System will auto-shutdown** (heater/cooler off)
2. **Check emergency log**: `/sd/emergency_log.txt`
3. **Run sensor diagnostics** to identify root cause
4. **Inspect hardware** based on diagnostic recommendations

### **Recovery Steps**
1. **Fix identified hardware issues**
2. **Test sensor reliability** with diagnostic tool
3. **Verify failsafe reset** works properly
4. **Restart experiment** only after confirming sensor health

## **Files Created/Modified**

### **New Files**
- `sensor_diagnostic.py` - Comprehensive sensor testing tool
- `temperature_failsafe.py` - Advanced failsafe protection system
- `BUG_ANALYSIS_AND_SOLUTION.md` - This documentation

### **Modified Files**
- `temp_controller.py` - Integrated failsafe protection system

## **Summary**

The "stuck at 19.1°C" bug was a **critical safety failure** caused by sensor failure combined with dangerous fallback logic. The implemented solution provides:

1. **Prevention**: Advanced sensor monitoring and diagnostics
2. **Detection**: Real-time stuck temperature detection (2-minute threshold)
3. **Protection**: Automatic emergency shutdown on unsafe conditions
4. **Analysis**: Comprehensive diagnostic tools for root cause identification

**This failsafe system will prevent the same type of overheating incident from occurring again.**

## **Next Steps**

1. **Run the sensor diagnostic** to identify current sensor health
2. **Test the failsafe system** to verify protection works
3. **Deploy to production** with confidence in improved safety
4. **Monitor system** for any new patterns or issues

The system is now significantly safer and will not repeat the dangerous overheating scenario you experienced.

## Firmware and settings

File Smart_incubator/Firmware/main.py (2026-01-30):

# main.py - Smart Incubator Control System
from machine import Pin, PWM
import time
import gc

# Defer heavy imports until after WiFi setup to save memory
# These will be imported later:
# from max31865 import init_max31865, read_temperature
# from sd_logger import ExperimentLogger, init_sd, deinit as sd_deinit
# from oled_display import OLEDDisplay
# from temp_controller import TempController
# from led_control import LED
# from vibration_control import Vibration
# from us_control import USController
# from run_experiment_cycle import run_experiment_cycle

# ---- PIN DEFINITIONS ----
TEC_PIN = 27  # TEC1 cooler control pin
LED_PIN = 25  # LED control pin
VIB_PIN = 16  # Vibration control pin
PTC_PIN = 33  # PTC heater control pin

# ---- GLOBAL VARIABLES ----
display = None
temp_ctrl = None
us_controller = None
led_pwm = None
vib_pwm = None
experiment_logger = None
wifi_ap = None
setup_server = None

# ---- EXPERIMENT CONFIGURATION (defaults, will be overridden by web config) ----
basal_temp = 23.0
heat_shock_temp = 32.0
us_type = "BOTH"
min_interval = 200      # minutes (not seconds!)
max_interval = 400      # minutes (not seconds!)
us_duration_seconds = 1800     # US window length in seconds (30 minutes)
heat_duration_seconds = 1800     # Heat shock duration in seconds (30 minutes)
correlation = 1.0     # Range [-1, 1]: -1 = no US, 0 = random, 1 = paired US before heat
experiment_name = "default_experiment"

def init_output_pins():
    """Initialize all output pins with PWM."""
    global led_pwm, vib_pwm
    
    # Initialize PWM pins
    led_pwm = PWM(Pin(LED_PIN))
    vib_pwm = PWM(Pin(VIB_PIN))
    
    # Set PWM frequency for all pins
    for pwm in [led_pwm, vib_pwm]:
        pwm.freq(1000)  # 1kHz PWM frequency
        pwm.duty_u16(0)  # Start with 0% duty cycle using 16-bit resolution
    
    return True

def init_temp_sensor():
    """Initialize temperature sensor."""
    from max31865 import init_max31865
    return init_max31865()

def init_display():
    """Initialize OLED display (optional - system continues if this fails)."""
    try:
        from oled_display import OLEDDisplay
        display = OLEDDisplay()
        print("[System] OLED display initialized successfully")
        return display
    except Exception as e:
        print(f"[WARNING] OLED display initialization failed: {e}")
        print("[WARNING] System will continue without display")
        return None

def init_temp_controller():
    """Initialize temperature controller."""
    from temp_controller import TempController
    # Reverted PID parameters to original values for 1kHz PWM frequency
    return TempController(PTC_PIN, TEC_PIN, kp=6.0, ki=0.02, kd=1.5)

def init_us_controller():
    """Initialize US controller."""
    global led_pwm, vib_pwm
    from led_control import LED
    from vibration_control import Vibration
    from us_control import USController
    led = LED(led_pwm)
    vibration = Vibration(vib_pwm)
    return USController(led, vibration)

def cleanup_globals():
    """Clean up global variables for retry attempts."""
    global display, temp_ctrl, us_controller, experiment_logger, wifi_ap, setup_server
    
    print("[Cleanup] Cleaning up resources...")
    
    # Stop WiFi AP if active
    if wifi_ap:
        try:
            wifi_ap.active(False)
            wifi_ap = None
        except:
            pass
    
    # Stop setup server if active
    if setup_server:
        try:
            setup_server.stop_server()
            setup_server = None
        except:
            pass
    
    # Deinitialize SD card SPI resources
    try:
        from sd_logger import deinit as sd_deinit
        sd_deinit()
    except:
        pass
    
    # Add delay to ensure SPI buses are fully released
    time.sleep(1)
    
    # Reset all global variables
    display = None
    temp_ctrl = None
    us_controller = None
    experiment_logger = None
    
    # Force garbage collection
    gc.collect()
    print("[Cleanup] Global variables reset and memory cleaned")

def init_system():
    """Initialize all system components."""
    global display, temp_ctrl, us_controller, experiment_logger
    global basal_temp, heat_shock_temp, us_type, min_interval, max_interval
    global us_duration_seconds, heat_duration_seconds, correlation, experiment_name
    
    try:
        print("\n=== Smart Incubator Control System ===")
        print("Initializing...")
        
        # Initialize output pins
        print("[System] Initializing output pins...")
        init_output_pins()
        print("[System] All output pins initialized and cleared")
        
        # Initialize temperature sensor
        print("[System] Initializing temperature sensor...")
        temp_sensor = init_temp_sensor()
        if not temp_sensor:
            raise Exception("Temperature sensor initialization failed")
        
        # Initialize display (optional - don't fail if this doesn't work)
        print("[System] Initializing display...")
        display = init_display()
        if display is None:
            print("[System] Continuing without display...")
        
        # Initialize temperature controller
        print("[System] Initializing temperature controller...")
        temp_ctrl = init_temp_controller()
        if not temp_ctrl:
            raise Exception("Temperature controller initialization failed")
        
        # Initialize US controller
        print("[System] Initializing US controller...")
        us_controller = init_us_controller()
        if not us_controller:
            raise Exception("US controller initialization failed")
        
        # Initialize SD card
        print("[System] Initializing SD card...")
        from sd_logger import ExperimentLogger, init_sd
        if not init_sd():
            raise Exception("SD card initialization failed")
        
        # Initialize experiment logger with current parameters
        print("[System] Initializing experiment logger...")
        us_duration_minutes = us_duration_seconds / 60.0
        heat_duration_minutes = heat_duration_seconds / 60.0

        experiment_params = {
            'experiment_name': str(experiment_name),
            'basal_temp': float(basal_temp),
            'heat_shock_temp': float(heat_shock_temp),
            'us_type': str(us_type),
            'min_interval': int(min_interval),
            'max_interval': int(max_interval),
            'us_duration': us_duration_minutes,
            'heat_duration': heat_duration_minutes,
            'us_duration_seconds': int(us_duration_seconds),
            'heat_duration_seconds': int(heat_duration_seconds),
            'correlation': float(correlation)
        }
        experiment_logger = ExperimentLogger(experiment_params)
        
        if not experiment_logger.init_experiment():
            raise Exception("Experiment logger initialization failed")
        
        print("[System] All components initialized successfully")
        return True
        
    except Exception as e:
        print(f"[ERROR] System initialization failed: {e}")
        return False

def wait_for_web_config():
    """
    Start WiFi AP and web server, wait for user to configure and start experiment.
    Returns the experiment configuration when user clicks start.
    """
    global wifi_ap, setup_server
    
    # Import WiFi modules now (deferred to save memory at boot)
    from wifi_setup import create_ap, get_unique_device_id
    from experiment_setup_server import ExperimentSetupServer
    
    # Force garbage collection before WiFi
    gc.collect()
    print(f"[Memory] Before WiFi: {gc.mem_free()} bytes")
    
    # Get unique device ID
    device_id = get_unique_device_id()
    print(f"[Setup] Device ID: {device_id}")
    
    # Create WiFi Access Point with unique SSID
    print("[Setup] Creating WiFi Access Point...")
    gc.collect()
    wifi_ap, ssid, ip = create_ap()
    
    gc.collect()
    print(f"[Memory] After WiFi: {gc.mem_free()} bytes")
    
    # Initialize temperature sensor for web display
    print("[Setup] Initializing temperature sensor...")
    try:
        from max31865 import init_max31865
        init_max31865()
    except Exception as e:
        print(f"[Setup] Temp sensor warning: {e}")
    
    gc.collect()
    
    # Create and start setup server
    setup_server = ExperimentSetupServer(device_id=device_id)
    setup_server.start_server(port=80)
    
    # Display connection info on OLED if available
    try:
        from oled_display import OLEDDisplay
        temp_display = OLEDDisplay()
        temp_display.clear()
        temp_display.show_message(f"WiFi: {ssid}", line=0)
        temp_display.show_message(f"Pass: incubator123", line=1)
        temp_display.show_message(f"IP: {ip}", line=2)
        temp_display.show_message("Waiting...", line=3)
    except:
        pass
    
    print(f"\nConnect to WiFi: {ssid}")
    print(f"Password: incubator123")
    print(f"Open: http://{ip}\n")
    
    # Wait for user to configure and start
    config = setup_server.serve_until_start()
    
    # Clean up server
    setup_server.stop_server()
    setup_server = None
    
    # Stop WiFi to free memory for experiment
    if wifi_ap:
        wifi_ap.active(False)
        wifi_ap = None
    
    gc.collect()
    mode = config.get('mode', 'experiment')
    if mode == 'stress':
        print("[Setup] Config received: stress test")
        print(f"[Setup] Test: {config.get('experiment_name', 'stress_test')}")
    else:
        print(f"[Setup] Config received: {config.get('experiment_name', 'experiment')}, corr={config.get('correlation', 0)}")
    print(f"[Memory] After cleanup: {gc.mem_free()} bytes")
    
    return config

def run_stress_test(config):
    """Run stress test protocol with web-configured parameters."""
    from main_test import (
        init_output_pins as test_init_pins,
        init_temp_sensor as test_init_sensor,
        init_display as test_init_display,
        init_temp_controller as test_init_temp_ctrl,
        init_us_controller as test_init_us_ctrl,
        run_stage,
        cleanup_globals as test_cleanup
    )
    from sd_logger import ExperimentLogger, init_sd
    import main_test
    
    # Apply web config to main_test module
    main_test.experiment_name = config.get('experiment_name', 'stress_test')
    main_test.training_temp = config['training_temp']
    main_test.challenge_temp = config['challenge_temp']
    main_test.training_duration_seconds = config['training_duration'] * 60
    main_test.challenge_duration_seconds = config['challenge_duration'] * 60
    main_test.us_led_intensity = config['us_led_intensity']
    main_test.us_vibration_intensity = config['us_vib_intensity']
    main_test.us_type = config['us_type']
    main_test.test_notes = config.get('notes', 'Web-configured stress test')
    
    print("\n[Stress Test] Initializing hardware...")
    
    test_init_pins()
    if not test_init_sensor():
        raise RuntimeError("Temperature sensor initialization failed")
    
    main_test.display = test_init_display()
    main_test.temp_ctrl = test_init_temp_ctrl()
    main_test.us_controller = test_init_us_ctrl()
    
    print("[Stress Test] Initializing SD card...")
    if not init_sd():
        raise RuntimeError("SD card initialization failed")
    
    # Create experiment logger with stress test params
    experiment_params = {
        "mode": "post_training_test",
        "experiment_name": config['experiment_name'],
        "training_temp": float(config['training_temp']),
        "training_duration_minutes": config['training_duration'],
        "challenge_temp": float(config['challenge_temp']),
        "challenge_duration_minutes": config['challenge_duration'],
        "us_led_intensity": int(config['us_led_intensity']),
        "us_vibration_intensity": int(config['us_vib_intensity']),
        "us_type": config['us_type'],
        "notes": config.get('notes', '')
    }
    main_test.experiment_logger = ExperimentLogger(experiment_params)
    if not main_test.experiment_logger.init_experiment():
        raise RuntimeError("Experiment logger initialization failed")
    
    print("[Stress Test] Starting protocol...")
    
    try:
        # Run training stage with US
        if not run_stage(
            stage_name="training_us",
            cycle_number=1,
            target_temp=main_test.training_temp,
            duration_seconds=main_test.training_duration_seconds,
            activate_us=True
        ):
            raise RuntimeError("Training stage failed")
        
        # Run heat challenge
        if not run_stage(
            stage_name="heat_challenge",
            cycle_number=2,
            target_temp=main_test.challenge_temp,
            duration_seconds=main_test.challenge_duration_seconds,
            activate_us=False
        ):
            raise RuntimeError("Challenge stage failed")
        
        print("\n[Stress Test] Protocol complete!")
        main_test.experiment_logger.finalize_experiment(status="completed")
        return True
        
    except Exception as e:
        print(f"[Stress Test] Error: {e}")
        if main_test.experiment_logger:
            main_test.experiment_logger.finalize_experiment(status="error", error=str(e))
        raise
    finally:
        if main_test.temp_ctrl:
            main_test.temp_ctrl.heater.turn_off()
            main_test.temp_ctrl.cooler.turn_off()
        if main_test.us_controller:
            main_test.us_controller.deactivate(main_test.us_type)
        if main_test.display:
            main_test.display.clear()


def main():
    """Main program loop."""
    global basal_temp, heat_shock_temp, us_type, min_interval, max_interval
    global us_duration_seconds, heat_duration_seconds, correlation, experiment_name
    global wifi_ap
    
    print("\n" + "="*60)
    print("   SMART INCUBATOR CONTROL SYSTEM v2.0")
    print("   WiFi Configuration Mode")
    print("="*60)
    
    # Print initial memory status
    gc.collect()
    print(f"[Memory] Initial free heap: {gc.mem_free()} bytes")
    
    # PHASE 1: Wait for web configuration
    print("\n[Phase 1] Starting WiFi setup mode...")
    try:
        config = wait_for_web_config()
        
        # Check if stress test mode was selected
        if config.get('mode') == 'stress':
            print("\n[Mode] Stress Test selected")
            print(f"  - Test Name: {config['experiment_name']}")
            print(f"  - Training: {config['training_temp']}°C for {config['training_duration']}m")
            print(f"  - Challenge: {config['challenge_temp']}°C for {config['challenge_duration']}m")
            print(f"  - US: LED {config['us_led_intensity']}% / Vib {config['us_vib_intensity']}%")
            
            try:
                run_stress_test(config)
                print("\n[Stress Test] Completed successfully!")
            except Exception as e:
                print(f"\n[Stress Test] Failed: {e}")
            return
        
        # Normal experiment mode
        experiment_name = config['experiment_name']
        correlation = config['correlation']
        basal_temp = config['basal_temp']
        heat_shock_temp = config['heat_shock_temp']
        us_type = config['us_type']
        min_interval = config['min_interval']
        max_interval = config['max_interval']
        us_duration_seconds = config['us_duration'] * 60  # Convert minutes to seconds
        heat_duration_seconds = config['heat_duration'] * 60  # Convert minutes to seconds
        
        print("\n[Config] Applied configuration:")
        print(f"  - Experiment: {experiment_name}")
        print(f"  - Correlation: {correlation}")
        print(f"  - Basal Temp: {basal_temp}°C")
        print(f"  - Heat Shock: {heat_shock_temp}°C")
        print(f"  - US Type: {us_type}")
        print(f"  - Interval: {min_interval}-{max_interval} min")
        print(f"  - US Duration: {us_duration_seconds}s")
        print(f"  - Heat Duration: {heat_duration_seconds}s")
        
    except Exception as e:
        print(f"[ERROR] Web configuration failed: {e}")
        print("[ERROR] Please restart device and try again.")
        return
    
    # PHASE 2: System initialization
    print("\n[Phase 2] Initializing system components...")
    
    # Retry logic for system initialization
    max_init_attempts = 5
    init_delay = 10  # seconds
    
    initialization_successful = False
    
    for attempt in range(1, max_init_attempts + 1):
        print(f"\n[System] Initialization attempt {attempt}/{max_init_attempts}")
        
        # Clean up from previous attempt (except first attempt)
        if attempt > 1:
            print("[System] Cleaning up from previous attempt...")
            cleanup_globals()
        
        if init_system():
            print("\nSystem initialized successfully!")
            initialization_successful = True
            break
        else:
            print(f"[ERROR] System initialization failed on attempt {attempt}")
            
            if attempt < max_init_attempts:
                print(f"[System] Waiting {init_delay} seconds before retry...")
                time.sleep(init_delay)
                
                # Clean up memory before retry
                gc.collect()
                print(f"[Memory] Free heap before retry: {gc.mem_free()} bytes")
            else:
                print(f"[ERROR] System initialization failed after {max_init_attempts} attempts!")
                print("[ERROR] Please check hardware connections and restart.")
    
    # Exit if initialization failed
    if not initialization_successful:
        print("[SYSTEM] Initialization failed. System will not start experiment cycles.")
        print("[SYSTEM] Please fix hardware issues and restart.")
        return
    
    # PHASE 3: Run experiment cycles
    print("\n[Phase 3] Starting experiment cycles...")
    print(f"Experiment: {experiment_name}")
    print(f"Correlation: {correlation}\n")
    
    # Configure US parameters (only if us_controller exists)
    if us_controller:
        us_controller.set_led_intensity(25)  # Set LED intensity to 25%
        us_controller.set_vib_intensity(100)  # Set vibration intensity to 100%
        us_controller.set_vib_interval("20:60")  # Set vibration interval to 20s ON, 60s OFF
        print("[System] US controller configured")
    else:
        print("[ERROR] US controller not available - cannot configure")
        return
    
    cycle_number = 1
    consecutive_errors = 0
    max_consecutive_errors = 3
    
    while True:
        try:
            # CRITICAL: Check SD health before starting cycle
            if experiment_logger and not experiment_logger.sd_write_ok:
                print(f"\n[CRITICAL] SD card is unhealthy - cannot start cycle {cycle_number}")
                print("[CRITICAL] Experiment halted to prevent data loss")
                experiment_logger.finalize_experiment(status='error', error='SD card write failures')
                break
            
            # Memory health check
            gc.collect()
            free_mem = gc.mem_free()
            print(f"\n[Memory] Free heap: {free_mem} bytes")
            if free_mem < 10000:  # Less than 10KB free
                print(f"[WARNING] Low memory detected! Free: {free_mem} bytes")
            
            print(f"\n{'='*50}")
            print(f"Starting Cycle {cycle_number}")
            print(f"{'='*50}\n")
            
            # Run experiment cycle with updated parameters
            from run_experiment_cycle import run_experiment_cycle
            run_experiment_cycle(
                cycle_number=cycle_number,
                display=display,
                temp_ctrl=temp_ctrl,
                us_controller=us_controller,
                min_interval=min_interval,
                max_interval=max_interval,
                us_type=us_type,
                us_duration=us_duration_seconds,
                correlation=correlation,
                heat_duration=heat_duration_seconds,
                basal_temp=basal_temp,
                heat_shock_temp=heat_shock_temp,
                log_interval=10,    # Log every 10 seconds
                experiment_logger=experiment_logger  # Pass the experiment logger
            )
            
            # Reset error counter on successful cycle
            consecutive_errors = 0
            cycle_number += 1
            
            # Add a small delay between cycles
            time.sleep(2)
            
            # Memory cleanup between cycles
            gc.collect()
            
        except Exception as e:
            consecutive_errors += 1
            print(f"\n[ERROR] Cycle {cycle_number} failed: {e}")
            print(f"[ERROR] Consecutive errors: {consecutive_errors}/{max_consecutive_errors}")
            
            # Attempt to recover by turning off all outputs
            if temp_ctrl:
                temp_ctrl.heater.turn_off()
                temp_ctrl.cooler.turn_off()
            if us_controller:
                us_controller.deactivate("BOTH")
                
            if consecutive_errors >= max_consecutive_errors:
                print("[ERROR] Too many consecutive errors. Stopping experiment.")
                if experiment_logger:
                    experiment_logger.finalize_experiment(status='error', error=f'Too many consecutive errors: {e}')
                break
                
            print("[ERROR] Attempting to recover...")
            cycle_number += 1
            time.sleep(5)  # Wait before retrying

if __name__ == "__main__":
    main()

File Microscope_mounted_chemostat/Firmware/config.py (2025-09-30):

# config.py - MCMC ESP-C Channel Controller Configuration
# Single-channel pump and LED control module

# ================== WIFI CONFIGURATION ==================
WIFI_SSID = "your_wifi_network"
WIFI_PASSWORD = "your_wifi_password"

# ================== MQTT CONFIGURATION ==================
# IP address of the Mac running mosquitto broker
MQTT_BROKER = "192.168.1.100"  
MQTT_PORT = 1883
MQTT_KEEPALIVE = 30  # Seconds

# Channel ID - MUST be set per ESP-C node (1, 2, or 3)
CHANNEL_ID = 1  # Change this for each ESP-C controller

# MQTT Topics (will be formatted with CHANNEL_ID)
TOPIC_CMD_PUMP_BASE = "cmd/chan{}/pump{}"      # cmd/chan1/pump1-4
TOPIC_CMD_LED = "cmd/chan{}/led"               # cmd/chan1/led
TOPIC_CMD_CALIBRATE = "cmd/chan{}/calibrate"   # cmd/chan1/calibrate
TOPIC_CMD_RESET_VOLUMES = "cmd/chan{}/reset_volumes"  # cmd/chan1/reset_volumes
TOPIC_CMD_KILL = "cmd/kill"                    # Global emergency stop
TOPIC_STAT_CHANNEL = "stat/chan{}"             # stat/chan1

# ================== HARDWARE CONFIGURATION ==================
# GPIO Pin assignments
PUMP_PINS = [25, 26, 27, 32]  # GPIO for pumps 1-4 PWM
LED_PIN = 33                  # LED pair PWM output
STATUS_LED_PIN = 2            # Built-in LED for status

# SD Card SPI pins
SD_CS_PIN = 5         # SD card chip select
SD_SCK_PIN = 18       # SPI clock
SD_MOSI_PIN = 23      # SPI MOSI  
SD_MISO_PIN = 19      # SPI MISO

# PWM Configuration
PWM_FREQUENCY = 1000  # 1kHz PWM frequency
PWM_RESOLUTION = 10   # 10-bit resolution (0-1023)

# ================== CONTROL PARAMETERS ==================
# Safety limits
MAX_COMMAND_DURATION = 3600   # 1 hour maximum pump run time (seconds)
MQTT_TIMEOUT_SEC = 60         # Failsafe timeout if MQTT silent
QUEUE_DEPTH = 5               # Maximum queued commands per pump

# Timing
CONTROL_FREQUENCY = 1.0       # 1Hz status reporting
STATUS_LED_FREQ_NORMAL = 2    # 2Hz status LED blink (normal)
STATUS_LED_FREQ_TIMEOUT = 10  # 10Hz status LED blink (timeout)

# ================== CALIBRATION DEFAULTS ==================
# Default calibration coefficients (ml/h = a * PWM% + b)
# These will be overridden by host calibration data
DEFAULT_CALIBRATION = {
    1: {"a": 2.5, "b": 0.1},  # Pump 1: ml/h = 2.5*PWM% + 0.1
    2: {"a": 2.4, "b": 0.0},  # Pump 2: ml/h = 2.4*PWM% + 0.0
    3: {"a": 2.6, "b": 0.2},  # Pump 3: ml/h = 2.6*PWM% + 0.2
    4: {"a": 2.3, "b": 0.1}   # Pump 4: ml/h = 2.3*PWM% + 0.1
}

# Calibration accuracy target
CALIBRATION_ERROR_TARGET = 5.0  # ±5% error target

# ================== LOGGING CONFIGURATION ==================
# SD card logging format
LOG_CSV_HEADER = "timestamp,pump,duty_pct,duration_s,led_duty_pct,volume_ml,command_id,event_type"

# Log rotation (new file each day)
LOG_ROTATE_DAILY = True

# Volume tracking
TRACK_VOLUMES = True          # Enable volume calculation and tracking
VOLUME_RESET_ON_BOOT = False  # Keep volume counters across reboots 

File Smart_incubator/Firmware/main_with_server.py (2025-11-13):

# main_with_server.py - Smart Incubator Control System with Web Server
from machine import Pin, PWM
import time
import gc
import _thread
from max31865 import init_max31865, read_temperature
from sd_logger import ExperimentLogger, init_sd
from oled_display import OLEDDisplay
from temp_controller import TempController
from led_control import LED
from vibration_control import Vibration
from us_control import USController
from run_experiment_cycle import run_experiment_cycle
from web_server import IncubatorWebServer

# ---- PIN DEFINITIONS ----
TEC_PIN = 27  # TEC1 cooler control pin
LED_PIN = 25  # LED control pin
VIB_PIN = 16  # Vibration control pin
PTC_PIN = 33  # PTC heater control pin

# ---- GLOBAL VARIABLES ----
display = None
temp_ctrl = None
us_controller = None
led_pwm = None
vib_pwm = None
experiment_logger = None
web_server = None
server_socket = None
last_snapshot_time = 0

# ---- SD CARD THREAD SAFETY ----
_sd_lock = _thread.allocate_lock()

def safe_sd_operation(operation_func, *args, **kwargs):
    """Thread-safe wrapper for SD card operations."""
    with _sd_lock:
        return operation_func(*args, **kwargs)

# ---- EXPERIMENT CONFIGURATION (from main.py) ----
basal_temp = 23.0
heat_shock_temp = 32.0
us_type = "BOTH"
min_interval = 5      # minutes (not seconds!)
max_interval = 10      # minutes (not seconds!)
us_duration = 1     # 30 seconds = 0.5 minutes
heat_duration = 2     # 2 minutes - increased for testing to see temp change
correlation = 1.0     # Range [-1, 1]: -1 disables US, 0 random, 1 paired

def init_output_pins():
    """Initialize all output pins with PWM."""
    global led_pwm, vib_pwm
    
    # Initialize PWM pins
    led_pwm = PWM(Pin(LED_PIN))
    vib_pwm = PWM(Pin(VIB_PIN))
    
    # Set PWM frequency for all pins
    for pwm in [led_pwm, vib_pwm]:
        pwm.freq(1000)  # 1kHz PWM frequency
        pwm.duty_u16(0)  # Start with 0% duty cycle using 16-bit resolution
    
    return True

def init_temp_sensor():
    """Initialize temperature sensor."""
    return init_max31865()

def init_display():
    """Initialize OLED display."""
    return OLEDDisplay()

def init_temp_controller():
    """Initialize temperature controller."""
    return TempController(PTC_PIN, TEC_PIN, kp=6.0, ki=0.02, kd=1.5)

def init_us_controller():
    """Initialize US controller."""
    global led_pwm, vib_pwm
    led = LED(led_pwm)
    vibration = Vibration(vib_pwm)
    return USController(led, vibration)

def init_system():
    """Initialize all system components - IDENTICAL TO main.py"""
    global display, temp_ctrl, us_controller, experiment_logger
    
    try:
        print("\n=== Smart Incubator Control System ===")
        print("Initializing...")
        
        # Initialize output pins
        print("[System] Initializing output pins...")
        init_output_pins()
        print("[System] All output pins initialized and cleared")
        
        # Initialize temperature sensor
        print("[System] Initializing temperature sensor...")
        temp_sensor = init_temp_sensor()
        if not temp_sensor:
            raise Exception("Temperature sensor initialization failed")
        
        # Initialize display
        print("[System] Initializing display...")
        display = init_display()
        if not display:
            raise Exception("Display initialization failed")
        
        # Initialize temperature controller
        print("[System] Initializing temperature controller...")
        temp_ctrl = init_temp_controller()
        if not temp_ctrl:
            raise Exception("Temperature controller initialization failed")
        
        # Initialize US controller
        print("[System] Initializing US controller...")
        us_controller = init_us_controller()
        if not us_controller:
            raise Exception("US controller initialization failed")
        
        # Initialize SD card with thread safety
        print("[System] Initializing SD card...")
        with _sd_lock:
            if not init_sd():
                raise Exception("SD card initialization failed")
        
        # Add delay to ensure SD card SPI is stable before experiment logger
        time.sleep_ms(200)
        print("[System] SD card stabilized")
        
        # Initialize experiment logger with thread safety
        print("[System] Initializing experiment logger...")
        experiment_params = {
            'basal_temp': float(basal_temp),
            'heat_shock_temp': float(heat_shock_temp),
            'us_type': str(us_type),
            'min_interval': int(min_interval),
            'max_interval': int(max_interval),
            'us_duration': int(us_duration),
            'heat_duration': int(heat_duration),
            'correlation': float(correlation)
        }
        
        with _sd_lock:
            experiment_logger = ExperimentLogger(experiment_params)
            if not experiment_logger.init_experiment():
                raise Exception("Experiment logger initialization failed")
        
        print("[System] All components initialized successfully")
        return True
        
    except Exception as e:
        print(f"[ERROR] System initialization failed: {e}")
        return False

def web_server_thread():
    """Web server thread function"""
    global web_server, server_socket
    
    try:
        while True:
            if server_socket:
                try:
                    client_socket, addr = server_socket.accept()
                    client_socket.settimeout(5.0)
                    
                    # Receive request
                    request = client_socket.recv(1024).decode('utf-8')
                    
                    # Handle request
                    response = web_server.handle_request(request)
                    
                    # Send response
                    client_socket.send(response.encode('utf-8'))
                    client_socket.close()
                    
                except Exception as e:
                    print(f"[Web Server] Client error: {e}")
                    try:
                        client_socket.close()
                    except:
                        pass
            else:
                time.sleep(1)
                
    except Exception as e:
        print(f"[Web Server] Thread error: {e}")
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

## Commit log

2025-09-30 Replaced to correct STL files
    [MCMC Temp control box.stl, MCMC pump table.stl, Multi channel chemostat v10 box.stl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]
2025-10-27 Fixed silent erros of SD card and temp sensor
    Fix: Add critical SD card and temperature sensor failure handling
    - Track SD write failures and halt experiment after 10 consecutive failures
    - Raise exceptions on temperature sensor faults to stop entire experiment
    - Improve experiment ID generation (YYYYMMDD_HHMMSS_corr format)
    - Add pre-cycle health checks for SD and memory monitoring
    - Reduce manifest memory footprint (100→50 entries)
    - Implement gradual temperature error recovery with increased tolerance
    Fixes issue where experiment ran 40+ cycles without saving data after
    SD card failure at cycle 8, eventually crashing from resource exhaustion.
    System now fails safely with clear error m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
    [boot.py, deploy_safe.py, format_sd_card.py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]
2025-10-28 Improve SD card formatting workflow and fix VS Code build task
    - Add dedicated SD Card Formatting section to README with clear method distinction:
    * Method 1: Full local reformat for new/corrupted cards (FAT32 MBR)
    * Method 2: ESP32 cleanup for quick data wipe
    * Platform-specific commands for macOS and Linux
    * Cross-reference to SD_CARD_FORMATTING_GUIDE.md
    - Fix VS Code default build task (Cmd+Shift+B) that appeared "canceled":
    * Add --yes flag to sync_firmware.py in tasks.json
    * Set SYNC_AUTO_YES=1 environment variable
    * Set cwd to workspaceFolder for proper path handling
    - Implement non-interactive deployment mode in sync_firmware.py:
    * Support --yes CLI flag and SYNC_AUT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
    [main.py, sync_firmware.py]
2025-10-29 refactor: harden firmware sync CLI and docs
    - replace ad-hoc calls to mpremote with a validated command resolver that probes the executable, python launchers, and honours MPREMOTE overrides
    - surface user-friendly errors when mpremote is unavailable and log the resolved command for transparency
    - refresh README quick start guidance with correlation overrides, VS Code shortcuts, and mpremote troubleshooting notes
    [sync_firmware.py]
2025-10-29 fixed err wrongly calling temp sensor
    [max31865.py, max31865_diagnostic.py, temp_controller.py]
2025-11-04 Refactor timing logic to use seconds for durations
    Updated US and heat shock durations to be specified and processed in seconds instead of minutes for improved precision and clarity. Adjusted all related calculations, logging, and parameter passing i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
2025-11-04 Improve temperature control robustness and logging
    Increased tolerance for invalid temperature readings and improved throttling of error/warning logs in run_experiment_cycle.py and temp_controller.py. Enhanced failsafe logic in temperature_failsafe.py to better distinguish between stuck and stable temperatures, added verbose logging control, and provided fallback stubs for missing modules. Updated .esp32_initialized to reflect new serial port.
    [run_experiment_cycle.py, temp_controller.py, temperature_failsafe.py]
2025-11-06 Enhance temperature failsafe logic and recovery handling
    Increases warning log interval in max31865 to reduce log spam. Improves sensor recovery config verification to allow for bits that clear automatically. Expands TemperatureFailsafe with new parameters for actuator thresholds, setpoint tolerance, and check intervals, and updates stuck temperature detection to avoid false positives when actuators are idle or temperature is within setpoint tolerance. Updates TempController to use new failsafe parameters and always print failsafe warnings.
    [max31865.py, sensor_recovery.py, temp_controller.py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]
2025-11-07 Refine MAX31865 register warning logic and add insights doc
    Improves the warning logic in max31865.py to only log zero register values if consecutive invalid reads are occurring, and allows selective flushing of warning counters when resetting invalid read counters. Also adds insights_for_paper.md, summarizing code–narrative gaps and recommendations for a related manuscript.
    [max31865.py]
2025-11-13 new correlation scheme and smoke test
    Key Updates
    Smart-incubator now supports continuous [-1,1] correlation: per-cycle behaviour is randomly selected as paired/no-US/random with correct probabilities and logged (Smart_incubator/Firmware/run_experiment_cycle.py (lines 36-394)). OLED output, experiment params, and logging metadata all handle floats cleanly (Smart_incubator/Firmware/main.py (lines 29-270), Smart_incubator/Firmware/main_with_server.py (lines 41-345), Smart_incubator/Firmware/oled_display.py (lines 30-63), Smart_incubator/Firmware/sd_logger.py (lines 65-95)).
    Web UI accepts numeric correlation with clamping, sync script can override float values, and legacy discrete modes were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
    [main.py, main_with_server.py, oled_display.py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]
2026-01-05 Add smart incubator analysis tools and batch scripts
    Added new figures, analysis scripts, and data files for the Smart Incubator project, including experimental paradigm graphics, batch analysis, inventory management, and post-run analysis modules. Upd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
2026-01-12 Add actuator test and interactive control scripts
    Introduce test_all.py for automated actuator/component testing and test_interactive.py for manual control and diagnostics of Smart Incubator hardware via Thonny REPL. These scripts facilitate hardwar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
2026-01-13 Add WiFi-based experiment setup and configuration
    Introduces phone-based WiFi configuration mode for the Smart Incubator. Adds experiment_setup_server.py and wifi_setup.py for web-based setup, updates main.py to support web configuration flow, and r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
2026-01-16 Preserve vibration timing when resuming US system
    Updated USController.activate to accept a reset_timing parameter, allowing vibration on/off cycle timing to be preserved when resuming after a brief pause. Modified run_experiment_cycle to use this feature when resuming the US system after logging.
    [run_experiment_cycle.py, us_control.py]
2026-01-23 Add stress test mode to experiment firmware
    Introduces a web-configurable stress test protocol alongside the standard experiment mode. Updates the web interface to support stress test configuration, adds logic to run the stress test in main.py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
2026-01-30 Support stress mode and set test name
    Handle a 'mode' field from web config and print a concise stress-test message when mode == 'stress'. Use config.get with sensible defaults to avoid KeyError for experiment_name and correlation. Also propagate experiment_name into main_test (defaulting to 'stress_test') when running the stress test so the test module receives the correct name. Logging of memory after cleanup remains unchanged.
    [main.py]
2026-04-28 Add discrete-cost scatter script; update ESP32
    Add a new plotting utility MBS_simulation/MBA vs BA sim/wrappers/plot_continuous_scatter_discrete_cost.py that reads continuous_summary.csv and produces a scatter plot with cost_multiplier discretize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
2026-06-02 Add hardware test, readiness soak, and UI updates
    Introduce a hardware preflight and continuous readiness soak plus related UI and SD improvements.
    - Add hardware_test.py: new run_hardware_test() that exercises OLED, SD, temp sensor, LED, vibration, cooler and heater with safety checks and reporting.
    - Add readiness_soak.py: long-running sensor/actuator soak test with logging to SD and OLED status display.
    - ExperimentSetupServer: add hardware test tab, hardware_config defaults, POST /hardware endpoint, temp_enabled flag, more robust request recv/send helpers, and helpers to expose hardware config/state.
    - main.py: detect temp sensor availability, pass temp_enabled to setup server, handle h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
2026-06-09 Add swarm deployment plan document
    Add SWARM_DEPLOYMENT_PLAN.md describing a host-driven workflow for fleet experiments. The document defines a swarm planner architecture, canonical swarm/spec/bulk/per-device config schemas and exampl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
